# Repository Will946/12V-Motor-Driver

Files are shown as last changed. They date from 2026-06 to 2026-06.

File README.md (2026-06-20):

# TB6612FNG Motor Driver Board

A single-IC dual-channel DC motor driver board built around the Toshiba **TB6612FNG**. It accepts a 12V motor supply and 3.3V logic supply, and drives two motors (or other DC loads) via direct GPIO control — no PWM enable line or standby control required.

## Board Render

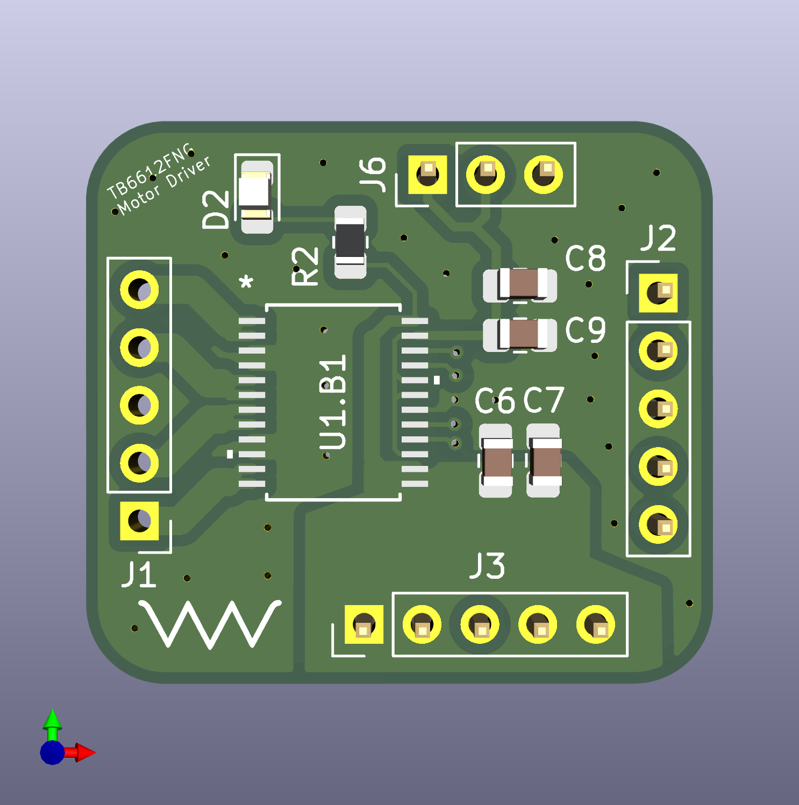
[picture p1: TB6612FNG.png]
PCB 3D render


## Schematic

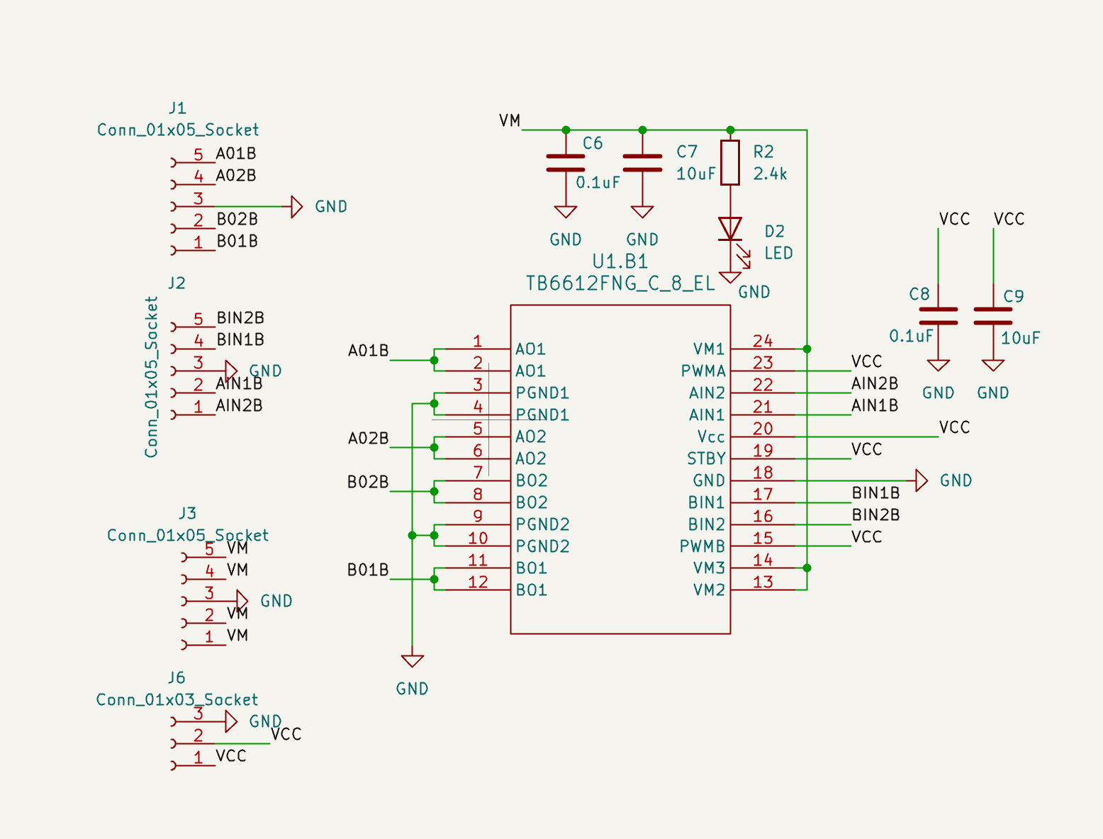
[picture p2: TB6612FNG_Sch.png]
Schematic


## Overview

This board breaks out one TB6612FNG dual H-bridge driver IC with all required support circuitry: power decoupling, a power-good LED indicator, and header connectors for power, control signals, and motor outputs. It's designed to be one repeatable "cell" in a multi-board or multi-instance motor control system. Multiple copies of this board can be powered from a shared 12V/3.3V/GND distribution and controlled independently from a microcontroller.

## What It's For

Driving small DC motors (e.g. brushed DC motors, peristaltic pump motors, gear motors) that:
- Run on 12V
- Draw up to ~1.2A continuous / 3.2A peak per channel
- Only need simple on/off or forward/reverse control (no onboard speed ramping required, though PWM control is possible if rewired)

Each board drives **two independent motors** (Channel A and Channel B).

## Key Design Decisions

- **STBY tied directly to VCC** — the IC is always active, no software standby control. Simplifies control to just the IN1/IN2 pins.
- **PWMA and PWMB tied directly to VCC** — both channels run at full enable at all times. Motor on/off and direction are controlled purely through AIN1/AIN2 and BIN1/BIN2 logic levels, not PWM gating.
- **No GPIO required for STBY/PWMA/PWMB** — frees up microcontroller pins; only 4 GPIOs are needed per board (2 per channel).
- **Multiple parallel pins for VM and GND** at the board connectors — spreads motor current across multiple contacts to reduce resistance and heat at the interconnect.
- **Single pin for VCC** — logic current draw is negligible (a few mA), so no need for parallel contacts.

## Bill of Materials (Key Components)

| Ref | Part | Function |
|-----|---|---|
| U1 | TB6612FNG (SSOP-24) | Dual H-bridge motor driver IC |
| C6 | 0.1 µF ceramic | High-frequency decoupling, VM rail (placed close to IC) |
| C7 | 10 µF | Bulk decoupling, VM rail |
| C8 | 0.1 µF ceramic | High-frequency decoupling, VCC rail (placed close to IC) |
| C9 | 10 µF | Bulk decoupling, VCC rail |
| R2 | 2.4 kΩ | Current-limiting resistor for power indicator LED (fed from VM) |
| D2 | LED | Power-on indicator, lit whenever VM is present |
| J1 | 5-pin socket | Motor output connector (AO1, AO2, BO1, BO2 + GND) |
| J2 | 5-pin socket | Control input connector (AIN1, AIN2, BIN1, BIN2 + GND) |
| J3 | 5-pin socket | VM power input connector (VM ×3, GND ×1 — parallel pins for current capacity) |
| J6 | 3-pin socket | VCC logic power connector (VCC ×2, GND ×1) |

## Pinout / Connector Reference

### J1 — Motor Outputs
| Pin | Net |
|-----|-----|
| 1 | BO1 |
| 2 | BO2 |
| 3 | GND |
| 4 | AO2 |
| 5 | AO1 |

### J2 — Control Inputs (from microcontroller)
| Pin | Net |
|-----|-----|
| 1 | AIN2 |
| 2 | AIN1 |
| 3 | GND |
| 4 | BIN1 |
| 5 | BIN2 |

### J3 — Motor Power Input (12V)
| Pin | Net |
|-----|-----|
| 1 | VM |
| 2 | VM |
| 3 | GND |
| 4 | VM |
| 5 | VM |

### J6 — Logic Power Input (3.3V)
| Pin | Net |
|-----|-----|
| 1 | VCC |
| 2 | VCC |
| 3 | GND |

## Operation

### Power-up
1. Connect 12V to J3 (VM) and 3.3V to J6 (VCC). Both share GND with the rest of the system.
2. The power indicator LED (D2) lights immediately whenever VM is present, confirming motor supply is live.
3. Because STBY, PWMA, and PWMB are hardwired to VCC, the IC is fully active as soon as VCC is applied — no initialization sequence or enable command is needed.

### Motor Control Logic

Each channel (A and B) is controlled by a pair of logic inputs:

| IN1 | IN2 | Output State |
|-----|-----|---|
| H | L | Motor runs forward |
| L | H | Motor runs reverse |
| L | L | Motor stopped (outputs low, coasting) |
| H | H | Short brake |

For simple on/off (single-direction) loads, tie the unused direction input low and drive only one input HIGH/LOW from the microcontroller to start/stop the motor.

### Control Pin Summary
- **AIN1 / AIN2** → Channel A direction/on-off control (from MCU GPIO)
- **BIN1 / BIN2** → Channel B direction/on-off control (from MCU GPIO)
- **STBY, PWMA, PWMB** → hardwired to VCC on this board, not exposed for external control

## Power Requirements

- **VM (Motor Supply):** 4.5V–13.5V, sized for 12V operation. Up to ~1.2A continuous / 3.2A peak per channel (2.4A/6.4A total for both channels, observing thermal limits).
- **VCC (Logic Supply):** 2.7V–5.5V, 3.3V intended. Draws only a few mA — no special supply requirements.
- **GND:** Common return for both VM and VCC. Shared across all connectors.

## Design Notes

- **Decoupling placement:** The 0.1 µF ceramic caps on both VM and VCC are placed as close as possible to the IC's power pins to suppress high-frequency switching noise. The 10 µF bulk caps support transient current demand during motor start and provide additional local energy storage.
- **Multiple VM/PGND IC pins** (VM1/VM2/VM3 and PGND1/PGND2) are all tied together on the PCB — this is standard practice for this package, distributing current across more pads to reduce localized resistance and heating.
- **Connector current sharing:** J3 (VM) and the GND return use multiple parallel pins specifically to handle motor current without overloading a single contact. J2 (control signals) and J6 (VCC) use single pins per net since signal/logic current is negligible.
- **No exposed thermal pad:** The SSOP-24 package has no bottom thermal pad, so copper traces may be routed underneath the IC footprint without conflict.

## Intended Use in a Larger System

This board is designed as a repeatable unit, multiple instances can be deployed in parallel, each independently controlled via its own J2 connector, while sharing a common 12V and 3.3V distribution through J3/J6. This allows a single microcontroller to drive many motor channels (4 GPIOs per board) without needing per-board enable/standby management.

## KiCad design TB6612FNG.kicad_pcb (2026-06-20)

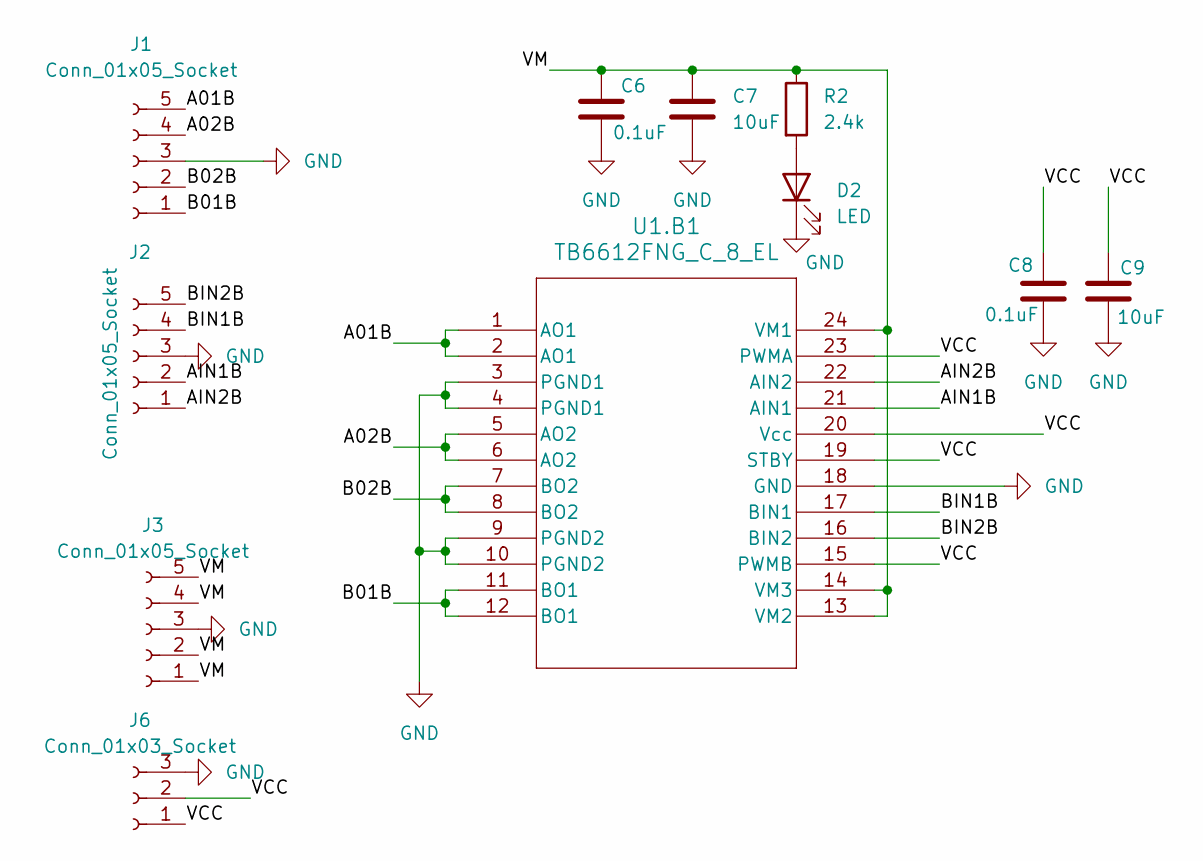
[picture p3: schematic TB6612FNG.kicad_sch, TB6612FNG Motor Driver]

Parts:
C6, C8: 0.1uF; C_0805_2012Metric_Pad1.18x1.45mm_HandSolder
C7, C9: 10uF; C_0805_2012Metric_Pad1.18x1.45mm_HandSolder
D2: LED; LED_0805_2012Metric_Pad1.15x1.40mm_HandSolder
J1, J2, J3: Conn_01x05_Socket; PinHeader_1x05_P2.54mm_Vertical
J6: Conn_01x03_Socket; PinHeader_1x03_P2.54mm_Vertical
R2: 2.4k; R_0805_2012Metric_Pad1.20x1.40mm_HandSolder
U1.B1: TB6612FNG_C_8_EL; TB6612FNG

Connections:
/A01B: J1.5, U1.B1.1 (AO1), U1.B1.2 (AO1)
/A02B: J1.4, U1.B1.5 (AO2), U1.B1.6 (AO2)
/AIN1B: J2.2, U1.B1.21 (AIN1)
/AIN2B: J2.1, U1.B1.22 (AIN2)
/B01B: J1.1, U1.B1.11 (BO1), U1.B1.12 (BO1)
/B02B: J1.2, U1.B1.7 (BO2), U1.B1.8 (BO2)
/BIN1B: J2.4, U1.B1.17 (BIN1)
/BIN2B: J2.5, U1.B1.16 (BIN2)
/VCC: C8.1, C9.1, J6.1, J6.2, U1.B1.15 (PWMB), U1.B1.19 (STBY), U1.B1.20 (Vcc), U1.B1.23 (PWMA)
/VM: C6.1, C7.1, J3.1, J3.2, J3.4, J3.5, R2.1, U1.B1.13 (VM2), U1.B1.14 (VM3), U1.B1.24 (VM1)
GND: C6.2, C7.2, C8.2, C9.2, D2.1 (K), J1.3, J2.3, J3.3, J6.3, U1.B1.3 (PGND1), U1.B1.4 (PGND1), U1.B1.9 (PGND2), U1.B1.10 (PGND2), U1.B1.18 (GND)
unnamed: D2.2 (A), R2.2

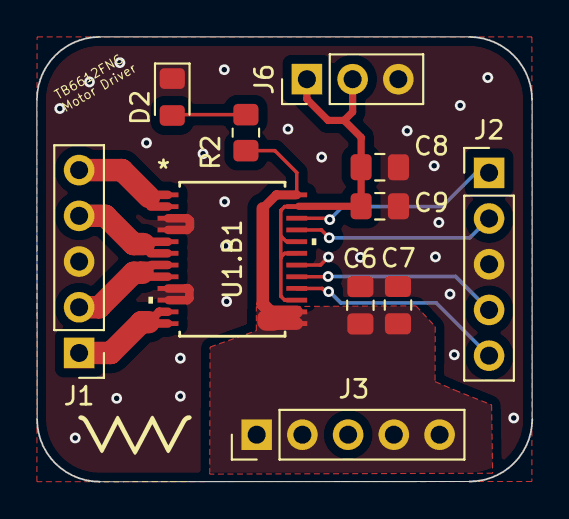
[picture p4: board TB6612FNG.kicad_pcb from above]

Board: 2 copper layers, 27.5 x 24.7 mm, 11 parts (0 on the bottom side), 12 nets.
